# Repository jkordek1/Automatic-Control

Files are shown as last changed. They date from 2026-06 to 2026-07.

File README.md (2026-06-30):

# Analog Control Systems Laboratory PCBs

A collection of educational printed circuit boards (PCBs) developed for laboratory exercises in **Automatic Control Systems**. The project demonstrates the implementation of fundamental analog transfer functions using passive components and operational amplifiers.

The boards are intended for university courses and provide a hands-on platform for studying the behavior of basic dynamic systems through practical experiments.

---

## Overview

This repository contains three independent laboratory boards:

| Board | Description |
|---|---|
| **RC Network** | Passive first-order RC circuit for studying time constants, transient response, and frequency response. |
| **P / PT1 / DT1** | Active analog circuit implementing proportional (P), first-order lag (PT1), and derivative (DT1) transfer functions using operational amplifiers. |
| **PI / I Controller** | Active analog circuit implementing an integrator (I) and proportional-integral (PI) controller. |

---

## Features

- Educational design for laboratory use
- Through-hole components for easy assembly and maintenance
- Banana connector interface for convenient measurements
- Powered from ±12 V laboratory power supply
- Designed in KiCad
- Fully documented schematics and PCB layouts

---

## Boards

### 1. RC Network

A passive first-order RC circuit used to investigate:

- Step response
- Time constant
- Charging and discharging behavior
- Frequency response
- First-order transfer functions

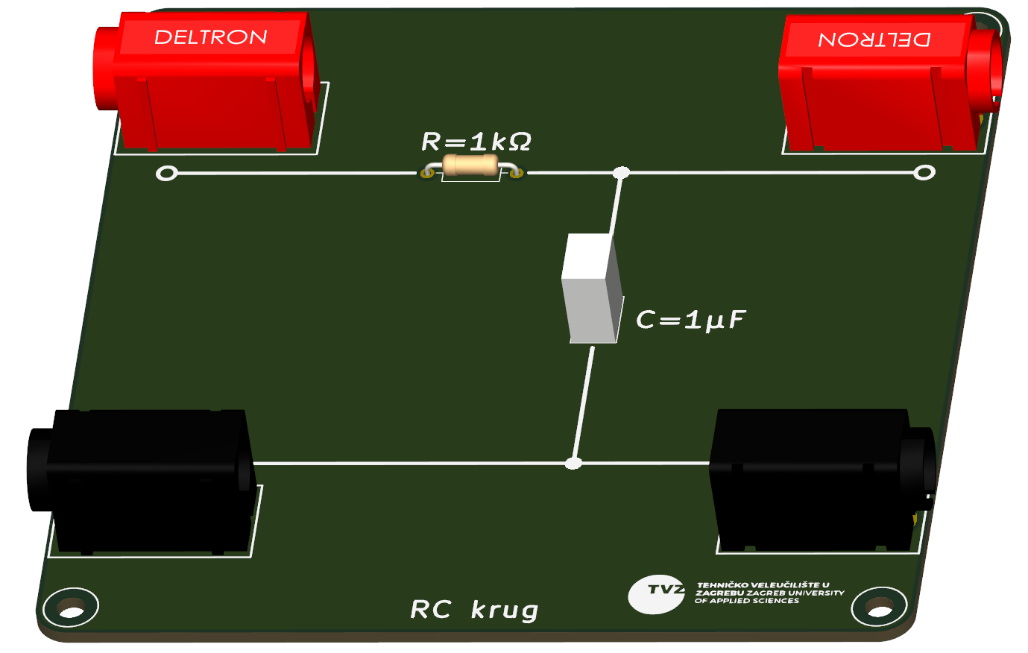
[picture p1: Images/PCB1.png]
PCB 1


---

### 2. P / PT1 / DT1 Board

An operational amplifier based circuit providing three selectable transfer functions:

- **P** – Proportional element
- **PT1** – First-order lag element
- **DT1** – Derivative element with first-order filtering

Jumper Configuration:
| Transfer Function | JP1 | JP2 |
|---|-----|-----|
| **PT1** | Pins **2–3** | Pins **2–3** |
| **DT1** | Pins **1–2** | Pins **1–2** |
| **P** | Pins **2–3** | Pins **1–2** |

This board allows students to compare the behavior of different dynamic systems under identical experimental conditions.

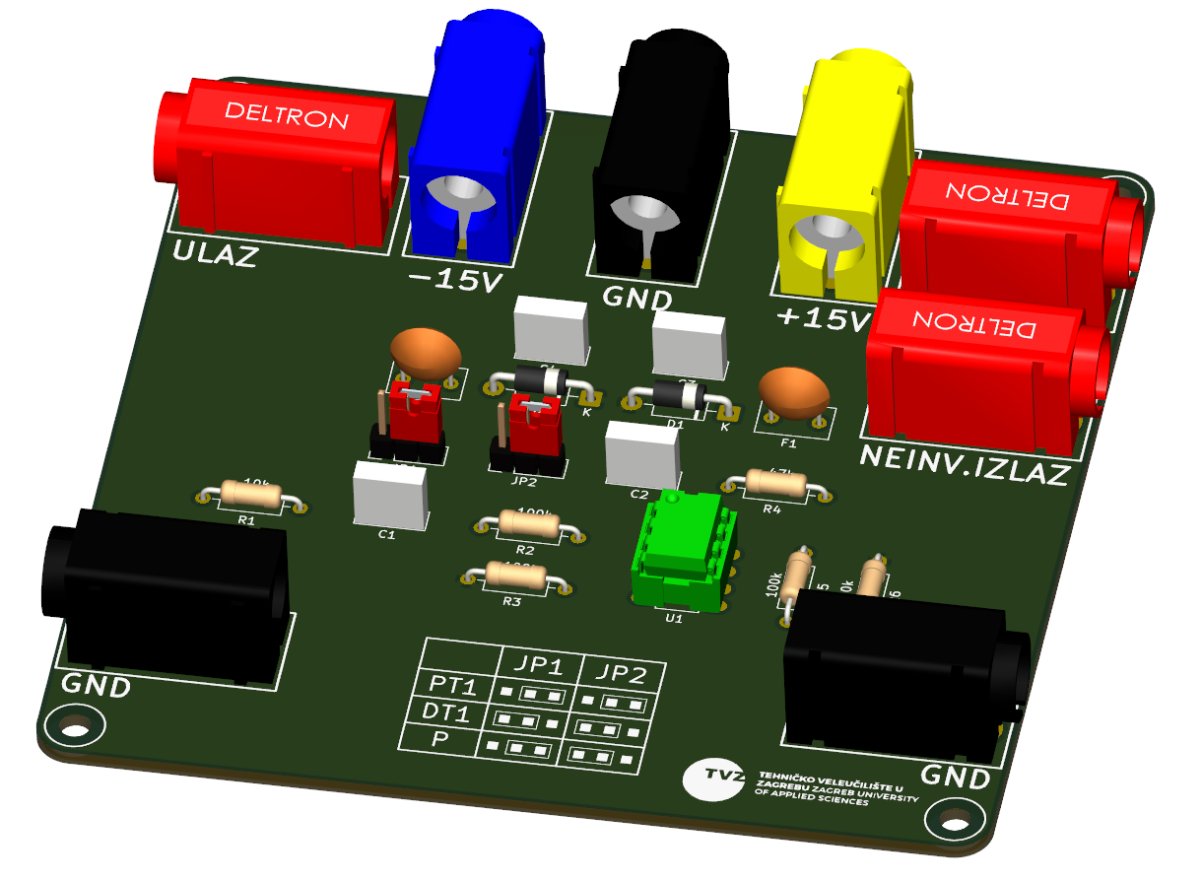
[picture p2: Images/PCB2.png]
PCB 2


---

### 3. PI / I Controller

An operational amplifier implementation of:

- **Integrator (I)**
- **Proportional–Integral (PI) controller**

Jumper Configuration:
| Transfer Function | JP1 |
|---|:---:|
| **PI** | 1–2 |
| **I** | 2–3 |

The board is intended for experiments involving closed-loop control and controller tuning.

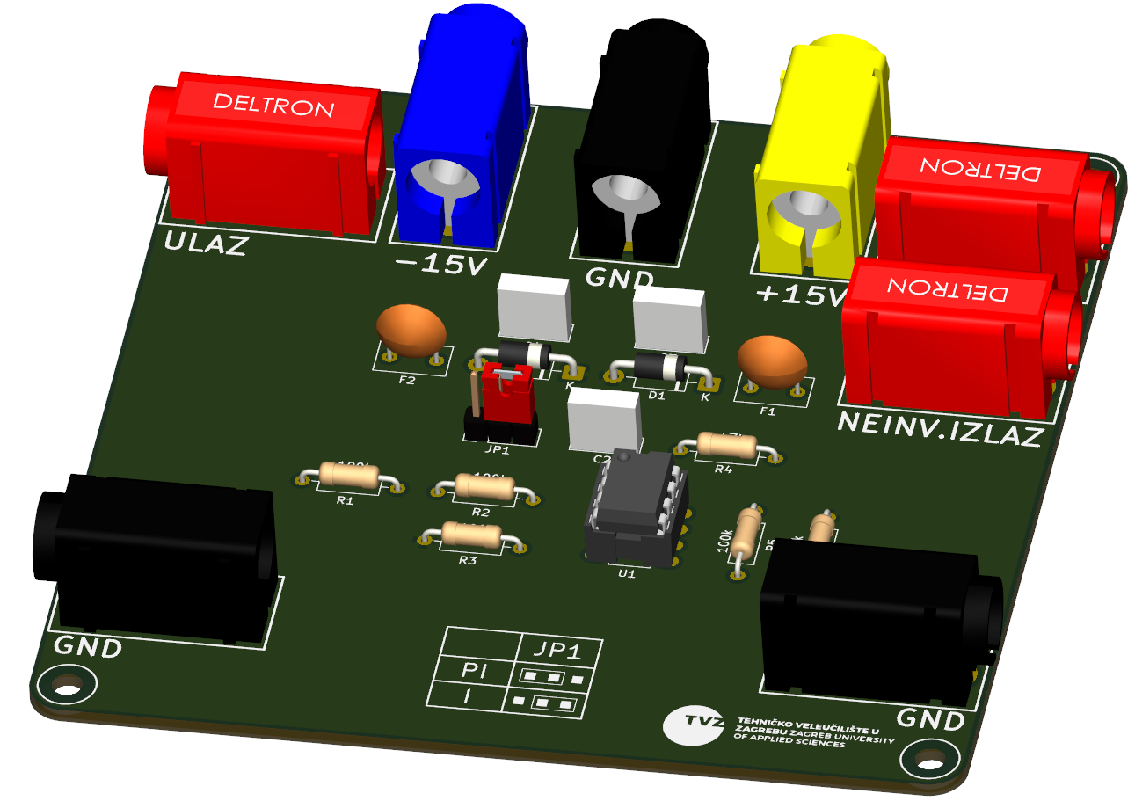
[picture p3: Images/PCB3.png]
PCB 3


## Software

Designed using **KiCad**.

The repository includes:

- Schematics
- PCB layouts
- Gerber files
- Bill of Materials (BOM)
- Manufacturing files

---

## Applications

These boards are suitable for:

- Automatic Control Systems laboratories
- Analog Electronics courses
- Control Engineering education
- Demonstrations of transfer functions
- Experimental verification of theoretical models

---

## Future Improvements

Planned additions include:

- Laboratory manuals
- Example experiments
- Simulation models
- Oscilloscope measurements
- Bode plots
- Assembly instructions

---

## License

This project is released under the MIT License.

---

## Author

Designed and developed for educational use in Automatic Control Systems laboratories.

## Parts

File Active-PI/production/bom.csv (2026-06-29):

Designator | Footprint | Quantity | Value | LCSC Part #
C2 | C_Rect_L7.2mm_W2.5mm_P5.00mm | 1 | 10nF
C3, C4 | C_Rect_L7.2mm_W2.5mm_P5.00mm | 2 | 0.1uF
D1, D2 | D_DO-41_SOD81_P10.16mm_Horizontal | 2 | 1N4007
F1, F2 | C_Disc_D7.5mm_W4.4mm_P5.00mm | 2 | 100mA
R1, R2, R3, R4, R5 | R_Axial_DIN0207_L6.3mm_D2.5mm_P10.16mm_Horizontal | 5 | 100k
R6 | R_Axial_DIN0207_L6.3mm_D2.5mm_P10.16mm_Horizontal | 1 | 47k
TP1, TP3, TP5 | DELTRON 4mm banana socket - red | 3 | TestPoint
TP10, TP2, TP4 | DELTRON 4mm banana socket - black | 3 | TestPoint
TP11 | DELTRON 4mm banana socket - blue | 1 | TestPoint
TP9 | DELTRON 4mm banana socket - yellow | 1 | TestPoint
U1 | DIP-8_W7.62mm_LongPads | 1 | TL072

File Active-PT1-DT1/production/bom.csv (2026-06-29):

Designator | Footprint | Quantity | Value | LCSC Part #
C1, C3, C4 | C_Rect_L7.2mm_W2.5mm_P5.00mm | 3 | 0.1uF
C2 | C_Rect_L7.2mm_W2.5mm_P5.00mm | 1 | 10nF
D1, D2 | D_DO-41_SOD81_P10.16mm_Horizontal | 2 | 1N4007
F1, F2 | C_Disc_D7.5mm_W4.4mm_P5.00mm | 2 | 100mA
R1 | R_Axial_DIN0207_L6.3mm_D2.5mm_P10.16mm_Horizontal | 1 | 10k
R2, R3, R4, R5 | R_Axial_DIN0207_L6.3mm_D2.5mm_P10.16mm_Horizontal | 4 | 100k
R6 | R_Axial_DIN0207_L6.3mm_D2.5mm_P10.16mm_Horizontal | 1 | 47k
TP1, TP3, TP5 | DELTRON 4mm banana socket - red | 3 | TestPoint
TP10, TP2, TP4 | DELTRON 4mm banana socket - black | 3 | TestPoint
TP11 | DELTRON 4mm banana socket - blue | 1 | TestPoint
TP9 | DELTRON 4mm banana socket - yellow | 1 | TestPoint
U1 | DIP-8_W7.62mm_LongPads | 1 | TL072

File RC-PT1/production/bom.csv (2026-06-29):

Designator | Footprint | Quantity | Value | LCSC Part #
C1 | C_Rect_L7.2mm_W5.0mm_P5.00mm | 1 | C
R1 | R_Axial_DIN0207_L6.3mm_D2.5mm_P10.16mm_Horizontal | 1 | R
TP1, TP3 | DELTRON 4mm banana socket - red | 2 | TestPoint
TP2, TP4 | DELTRON 4mm banana socket - black | 2 | TestPoint

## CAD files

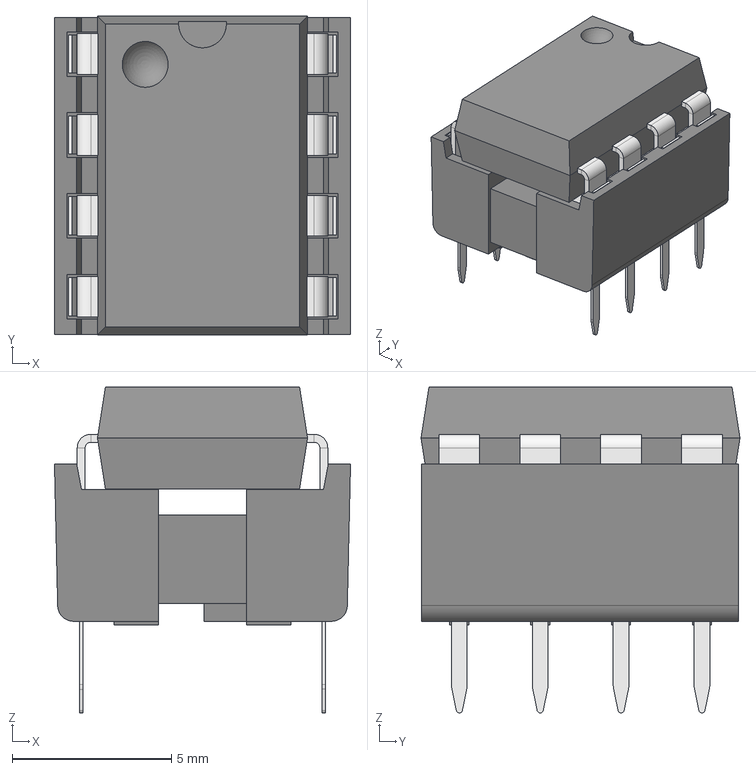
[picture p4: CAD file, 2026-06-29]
Active-PI/3Dmodels/DIP8N socket with IC.step
9.30 x 10.0 x 10.2 mm
DIP8N socket
DIP8N IC

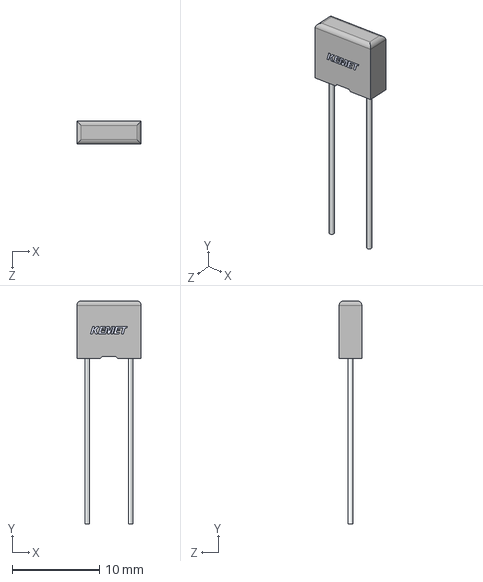
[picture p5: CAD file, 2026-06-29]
Active-PI/3Dmodels/R82DC3100DQ50J.step
7.40 x 25.6 x 2.60 mm

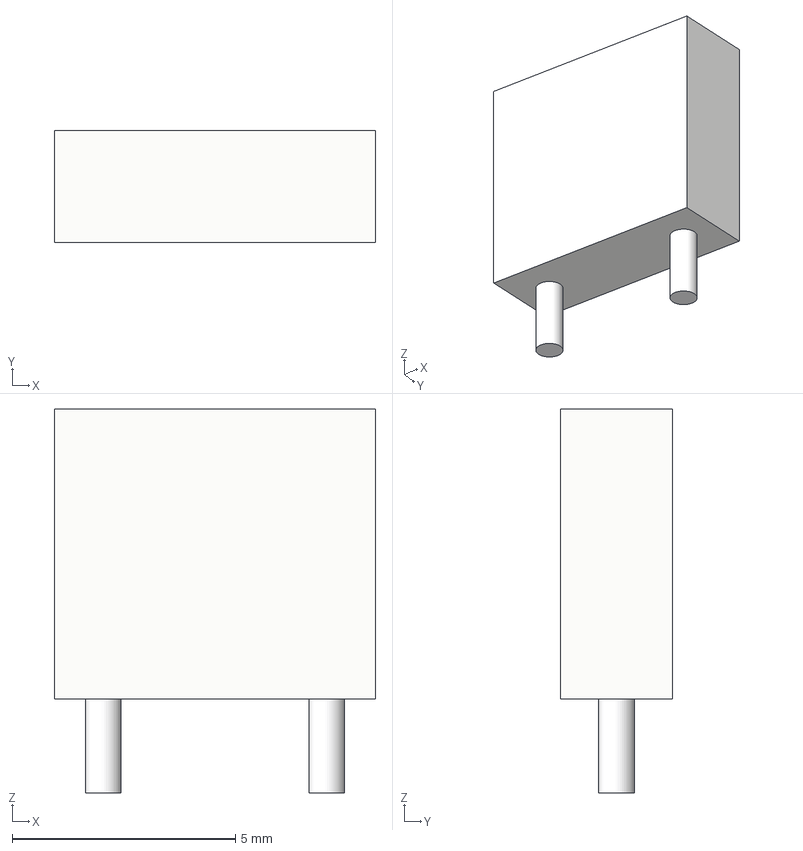
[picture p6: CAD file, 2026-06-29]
Active-PI/3Dmodels/Capacitor 7.2x2.5x6.5mm.step
7.20 x 2.50 x 8.60 mm

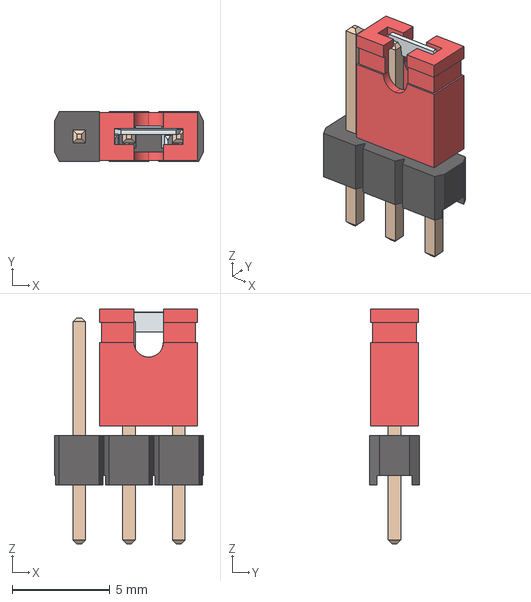
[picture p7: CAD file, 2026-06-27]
Active-PI/3Dmodels/Jumper_1x3.stp
7.62 x 2.54 x 12.0 mm

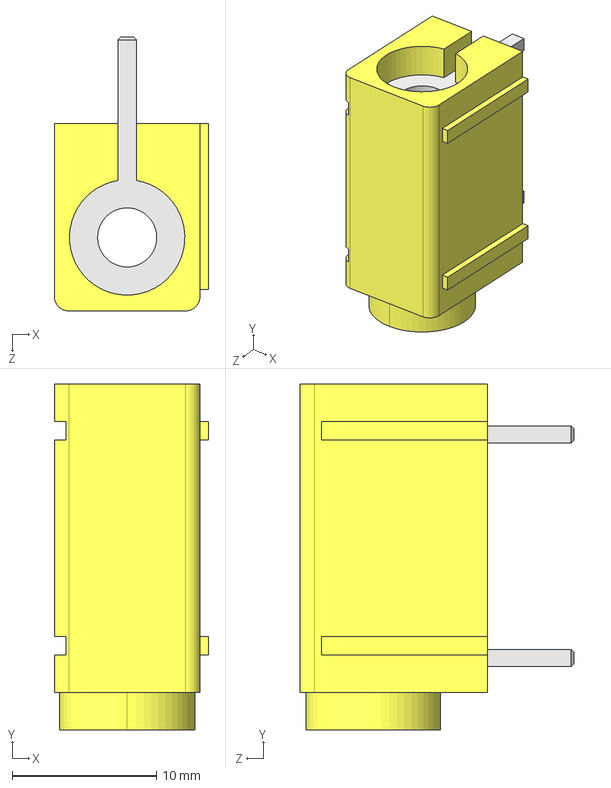
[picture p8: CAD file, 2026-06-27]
Active-PI/3Dmodels/AB2_90DEG_4MM_JACK_PTH-YEL.step
10.7 x 24.0 x 19.0 mm

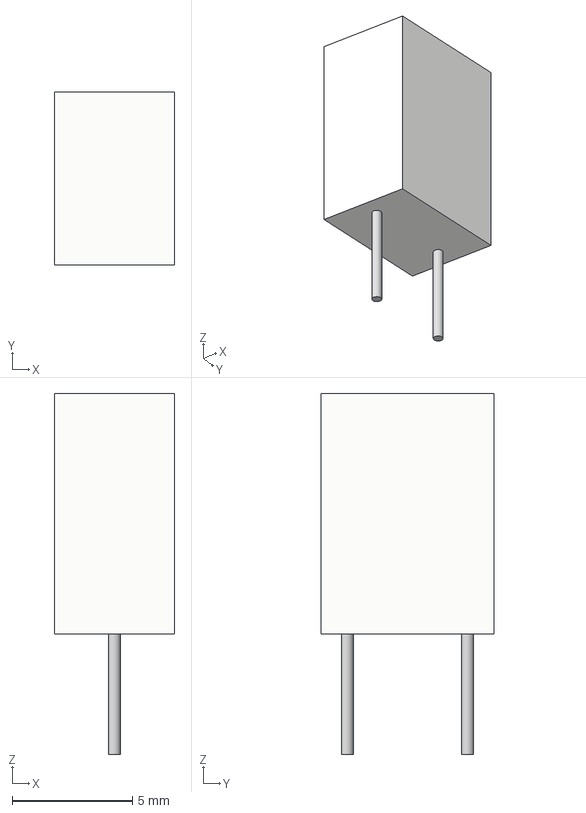
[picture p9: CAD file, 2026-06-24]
Active-PI/3Dmodels/Capacitor_7.2x5mm.step
5.00 x 7.20 x 15.0 mm

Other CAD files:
Active-PI/3Dmodels/AB2_90DEG_4MM_JACK_PTH-BLUE.step
Active-PI/3Dmodels/AB2_90DEG_4MM_JACK_PTH-BLK.STEP

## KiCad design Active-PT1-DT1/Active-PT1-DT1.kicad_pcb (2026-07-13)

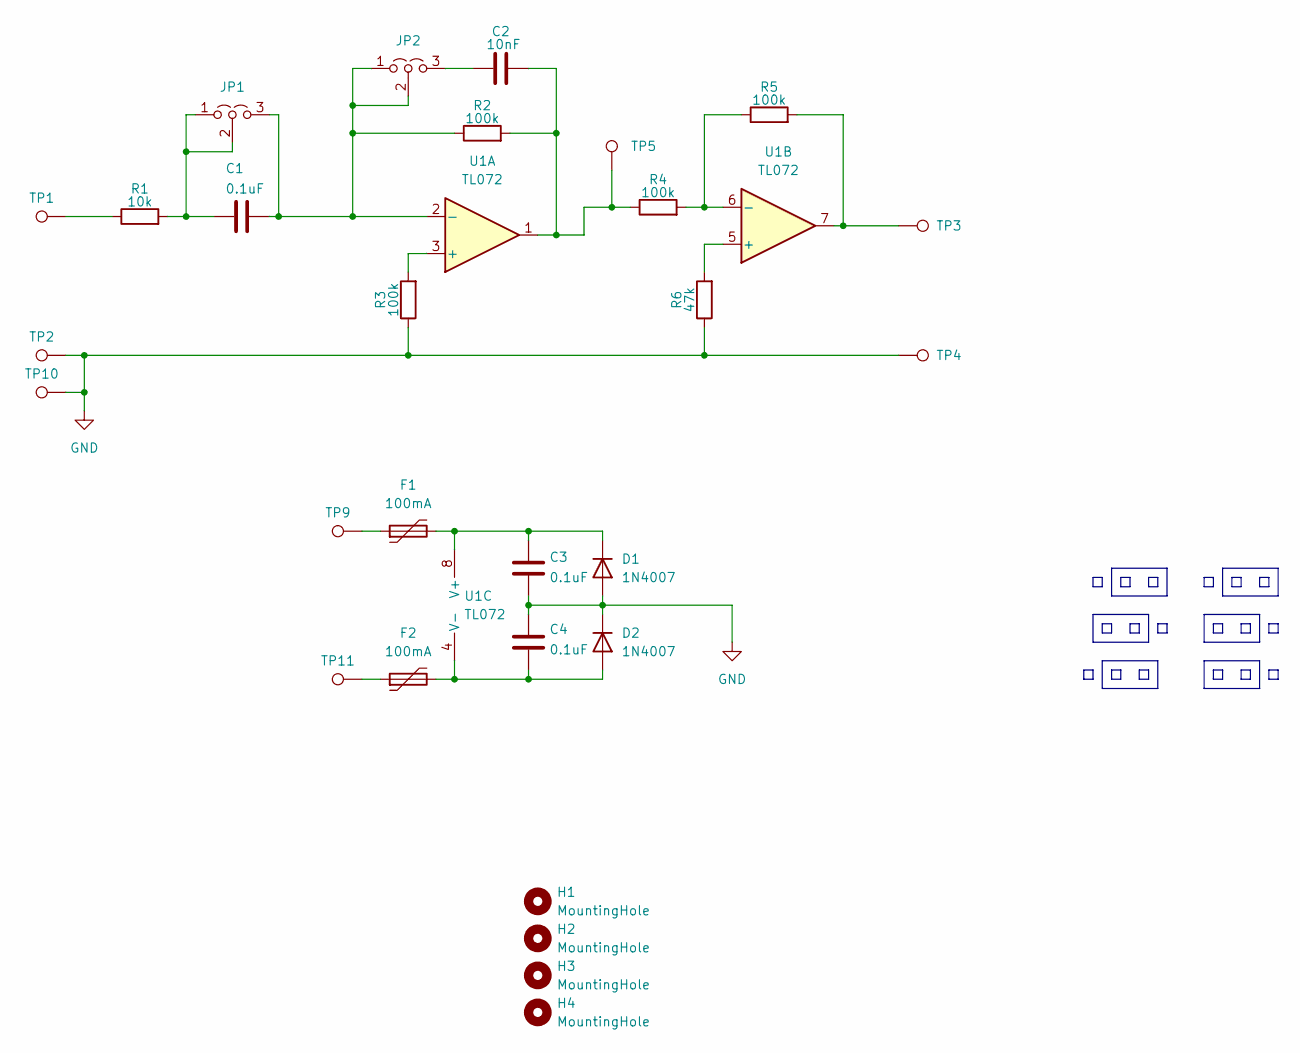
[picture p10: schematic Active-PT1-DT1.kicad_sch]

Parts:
C1, C3, C4: 0.1uF; C_Rect_L7.2mm_W2.5mm_P5.00mm
C2: 10nF; C_Rect_L7.2mm_W2.5mm_P5.00mm
D1, D2: 1N4007; D_DO-41_SOD81_P10.16mm_Horizontal
F1, F2: 100mA; C_Disc_D7.5mm_W4.4mm_P5.00mm
H1, H2, H3, H4: MountingHole; MountingHole_3.2mm_M3
JP1, JP2: Jumper_3_Open; Jumper_1x03
R1: 10k; R_Axial_DIN0207_L6.3mm_D2.5mm_P10.16mm_Horizontal
R2, R3, R4, R5: 100k; R_Axial_DIN0207_L6.3mm_D2.5mm_P10.16mm_Horizontal
R6: 47k; R_Axial_DIN0207_L6.3mm_D2.5mm_P10.16mm_Horizontal
TP1, TP3, TP5: TestPoint; DELTRON 4mm banana socket - red
TP2, TP4, TP10: TestPoint; DELTRON 4mm banana socket - black
TP9: TestPoint; DELTRON 4mm banana socket - yellow
TP11: TestPoint; DELTRON 4mm banana socket - blue
U1: TL072; DIP-8_W7.62mm_LongPads

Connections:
GND: C3.2, C4.1, D1.2 (A), D2.1 (K), R3.1, R6.1, TP2.1 (1_1), TP4.1 (1_1), TP10.1 (1_1)
unnamed: C2.2, R2.2, R4.1, TP5.1 (1_1), U1.1
unnamed: C3.1, D1.1 (K), F1.2, U1.8 (V+)
unnamed: C4.2, D2.2 (A), F2.2, U1.4 (V-)
unnamed: F1.1, TP9.1 (1_1)
unnamed: F2.1, TP11.1 (1_1)
unnamed: C1.1, JP1.1 (A), JP1.2 (C), R1.2
unnamed: C1.2, JP1.3 (B), JP2.1 (A), JP2.2 (C), R2.1, U1.2 (-)
unnamed: C2.1, JP2.3 (B)
unnamed: R1.1, TP1.1 (1_1)
unnamed: R5.2, TP3.1 (1_1), U1.7
unnamed: R3.2, U1.3 (+)
unnamed: R6.2, U1.5 (+)
unnamed: R4.2, R5.1, U1.6 (-)

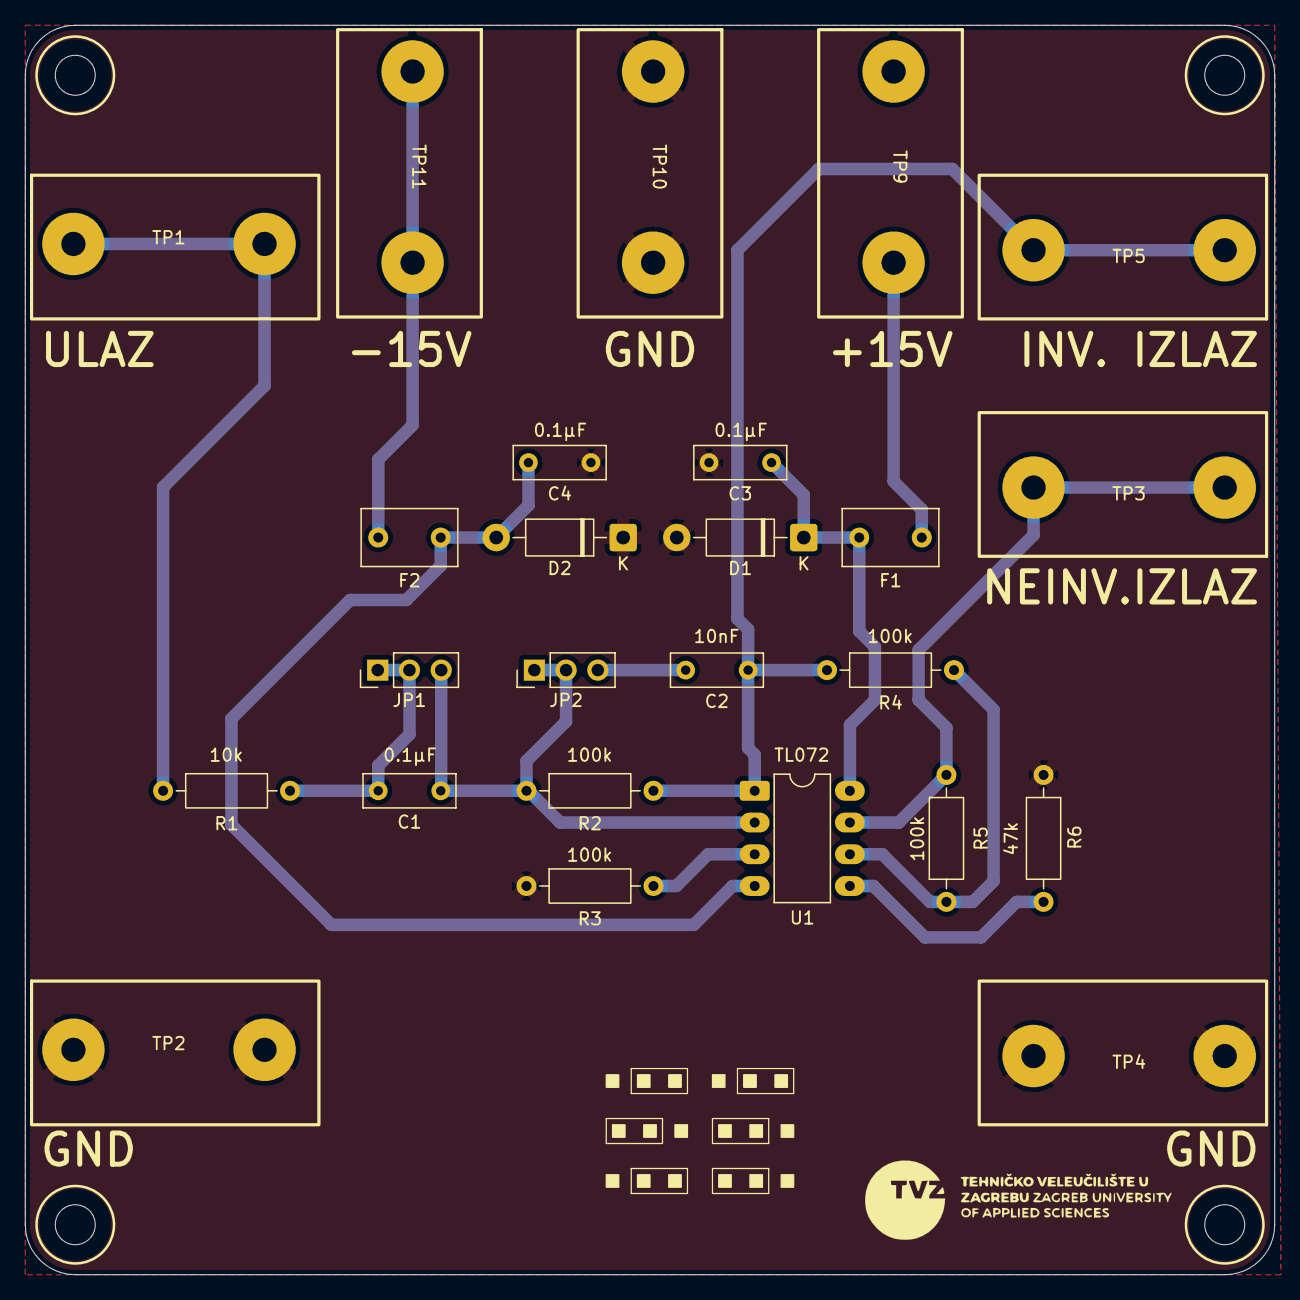
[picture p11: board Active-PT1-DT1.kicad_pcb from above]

Board: 2 copper layers, 100.0 x 100.0 mm, 29 parts (0 on the bottom side), 14 nets.

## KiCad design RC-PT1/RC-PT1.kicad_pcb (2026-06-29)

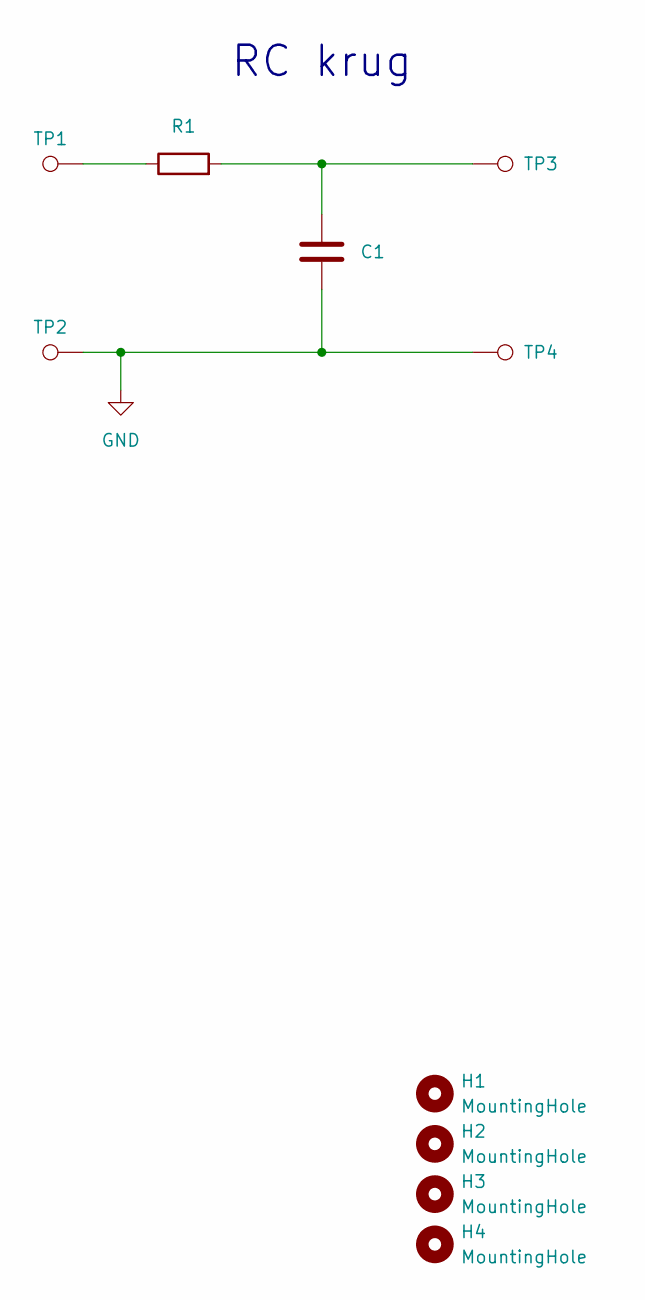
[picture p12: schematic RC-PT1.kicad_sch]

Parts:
C1: C; C_Rect_L7.2mm_W5.0mm_P5.00mm
H1, H2, H3, H4: MountingHole; MountingHole_3.2mm_M3
R1: R; R_Axial_DIN0207_L6.3mm_D2.5mm_P10.16mm_Horizontal
TP1, TP3: TestPoint; DELTRON 4mm banana socket - red
TP2, TP4: TestPoint; DELTRON 4mm banana socket - black

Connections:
GND: C1.2, TP2.1 (1_1), TP4.1 (1_1)
unnamed: C1.1, R1.2, TP3.1 (1_1)
unnamed: R1.1, TP1.1 (1_1)

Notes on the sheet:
RC krug

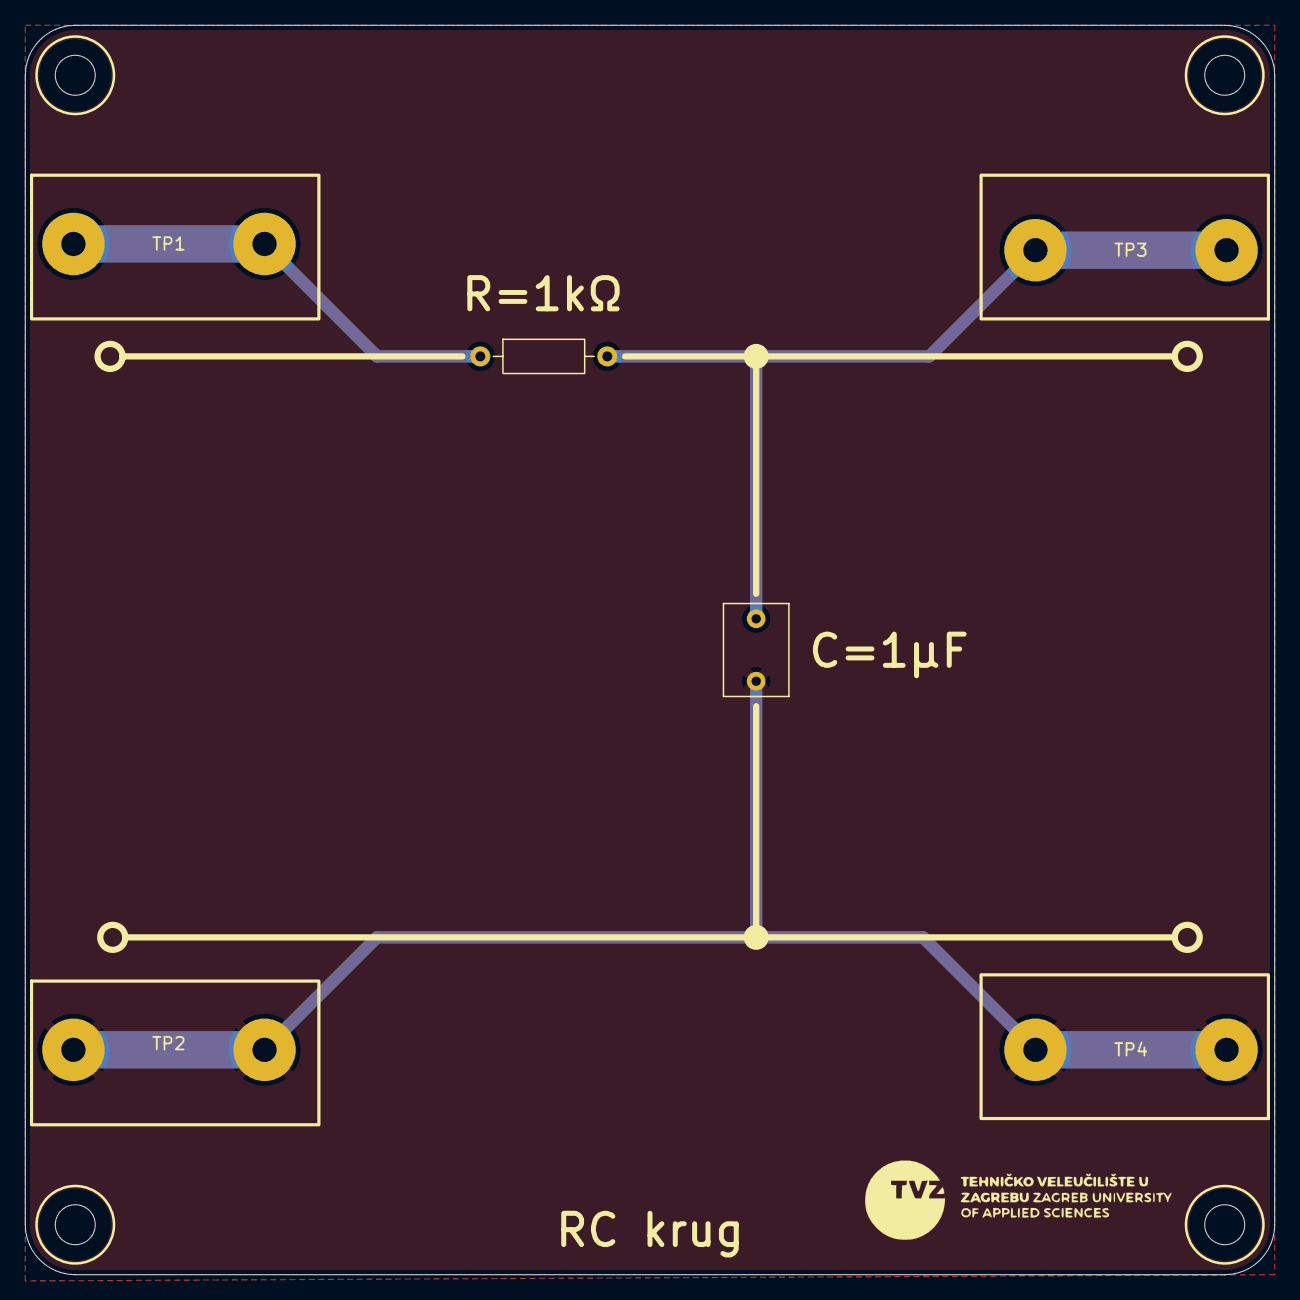
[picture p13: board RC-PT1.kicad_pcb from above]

Board: 2 copper layers, 100.0 x 100.0 mm, 10 parts (0 on the bottom side), 3 nets.

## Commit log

2026-06-23 Pastivni PT1
    [AB2_90DEG_4MM_JACK_PTH-BLK.STEP, RC-PT1.kicad_pcb, RC-PT1.kicad_sch]
2026-06-24 DT1 added
    [Capacitor_7.2x5mm.step, RC-DT1.kicad_pcb, RC-DT1.kicad_sch]
2026-06-25 remove DT1
    [RC-DT1.kicad_pcb, RC-DT1.kicad_sch, RC-PT1.kicad_pcb]
2026-06-25 Dodan aktivni član PT1/DT1
    [Active-PT1-DT1.kicad_pcb, Active-PT1-DT1.kicad_sch, KEYS4952.STEP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]
2026-06-27 Fix libraries
    [AB2_90DEG_4MM_JACK_PTH-BLK.STEP, AB2_90DEG_4MM_JACK_PTH-BLUE.step, AB2_90DEG_4MM_JACK_PTH-YEL.step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]
2026-06-29 PT1/DT1/P complete
    [Active-PT1-DT1.kicad_pcb, Active-PT1-DT1.kicad_sch, Capacitor 7.2x2.5x6.5mm.step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]
2026-07-10 Step file created
    [.step]
2026-07-13 fix label
    [Active-PT1-DT1.kicad_pcb]
